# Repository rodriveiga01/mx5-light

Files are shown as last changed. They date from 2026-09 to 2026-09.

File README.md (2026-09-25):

# NA-Wink

Prototype controller for MX-5 pop-up headlights: ESP32 firmware, hardware
design, and companion app.

- `firmware/` — controller, BLE protocol, and host model.
- `hardware/` — harness, pinout, KiCad design, and circuit notes.
- `simulator/` — motor-free behavioral simulation.

Prototype only. Vehicle pinout, wiring, and hardware behavior still need
bench and donor-car validation; see `hardware/kicad/README.md`.

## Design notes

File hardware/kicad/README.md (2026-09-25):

# KiCad design

Sources: `na-wink.kicad_sch` (schematic) and `na-wink.kicad_pcb` (layout
draft). This is a review draft, not fabrication-ready.

- ERC: 0 errors. DRC: 22 unconnected GND items because CLI checks do not fill zones.
- Library remapping is required. Relay footprints are placeholders and must be corrected.
- Connector fit, motor current, relay rating, and relay polarity remain unverified.
- Do not order a board until layout checks and bench validation HV1–HV4 pass.

Reports: `hardware/exports/erc.rpt` and `hardware/exports/drc.rpt`.

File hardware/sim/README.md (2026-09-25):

# Circuit notes

No SPICE run or analog results are available. Motor parameters and validated
vendor models are missing; `protection-frontend.cir.BLOCKED` is a template,
not a runnable simulation.

- `RESULTS.md` — missing measurements and evidence status.
- `tvs-entry-notes.md`, `buck-ldo-notes.md`, `relay-coil-notes.md` — design
  notes only; bench checks are still required.

Enable simulation only after measuring the real motor and adding validated
TVS, buck, and relay models. Save actual results under `hardware/exports/`.

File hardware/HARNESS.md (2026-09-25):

# Harness (plug-and-play, never cut factory wiring)

Two adapter legs sit between the factory connectors and the motors. Relays
de-energized = OEM straight through, so unpowered the car behaves stock
(HV1 validation, NOT RUN).

## Wires (PROPOSED — meter on the donor car before crimping)

| Leg | Wire | Size | Note |
|---|---|---|---|
| A (car) | VBAT | 2.5 mm² + 1.0 pigtail | red, fused 10 A on module |
| A | GND | 2.5 mm² + 1.0 pigtail | black, chassis star bolt |
| A | OEM_L_A/B, OEM_R_A/B | 1.5 mm² + 1.0 pigtail | twisted pairs, < 60 cm |
| A | BTN_SENSE | 0.5 mm² | yellow, opto tap only, 0.5 A inline fuse |
| B (motors) | MOT_x_A/B | 1.5 mm² + 1.0 pigtail | relay common to motor |
| B | SHIELD/GND | 0.5 mm² | drain at module end only |

Rule: NEVER crimp 2.5/1.5 mm² into an MX120G terminal (family max 1.0 mm²).
Join runs to pigtails with ultrasonic splice + adhesive heat-shrink, 10 joints.

## Connectors (candidates — fit NOT verified, meter before mating)

| Ref | Module side | Mating side |
|---|---|---|
| J1 | MX120G 8-pos sealed plug | 8-pos receptacle + terminals + cavity plugs |
| J2/J3 | MX120G 3-pos | matching 3-pos + terminals |
| J_PROG | 1x06 P2.54 header | bench jumpers only |

## Build rules

1. Crimp with the manufacturer tool, pull-test every crimp. Never solder terminals.
2. Sealed shells + cavity plugs on empty positions; loom + boots on both shells.
3. Label every leg (L / R / CAR / MOTOR). Removal = unplug, no trace remains.
4. Verify unpowered: < 1 Ω OEM→MOT per pole, > 10 MΩ pin-to-shell.

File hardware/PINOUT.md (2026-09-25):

# Pinout (PROPOSED — meter every conductor before mating)

## J1 — car side (8-pos sealed)

| Pin | Signal | Note |
|---|---|---|
| 1 | VBAT | fused 10 A on module |
| 2 | GND | chassis star point |
| 3–4 | OEM_L_A / OEM_L_B | relay NC poles |
| 5–6 | OEM_R_A / OEM_R_B | relay NC poles |
| 7 | BTN_SENSE | opto tap, high-Z only |
| 8 | AUX_GND (RESERVED) | unconnected — do NOT wire buttons here |

## J2/J3 — motor sides

| Pin | Signal | Note |
|---|---|---|
| 1–2 | MOT_x_A / MOT_x_B | relay common (NC = OEM, NO = drive) |
| 3 | SHIELD/GND | drain |

NC = de-energized OEM path. Check: pin numbering vs shell keying, NC/NO
orientation, coil polarity + flyback direction, TVS at entry, fuse access.

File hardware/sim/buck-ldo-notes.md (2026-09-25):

# Buck and LDO notes

Proposed supply: protected 12 V → 5 V buck (LM46002-Q1) → 3.3 V LDO
(KF33BD-class). Relay coils use 5 V; the MCU uses 3.3 V. Values and parts
must be checked against datasheets before build.

- Use the buck datasheet design for inductor and compensation; verify load
  steps and 3.3 V stability on the bench.
- Check 3.3 V temperature and regulation during a 60 °C, 30-minute soak.
- Standby target is under 5 mA; not measured.

No SPICE result is claimed. Vendor transient models and bench measurements
are not available.

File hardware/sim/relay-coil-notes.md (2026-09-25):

# Relay coil notes

Four 5 V relay coils use NPN low-side drivers and flyback diodes. GPIO LOW
should leave each relay de-energized on the OEM path; confirm boot behavior
with a scope before vehicle use.

The proposed 560 Ω base resistor improves drive margin over 1 kΩ, but coil
current and transistor saturation must be checked against the final relay
datasheet. Relay and motor inrush behavior is unmeasured. Firmware staggers
commands by at least 150 ms; this does not replace hardware validation.

No SPICE result is claimed. Confirm coil data and suppression on the bench.

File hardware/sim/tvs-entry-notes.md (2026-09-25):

# Power-entry protection notes

Proposed path: J1 → 10 A fuse → reverse-battery block → protected 12 V rail.
A bidirectional SMBJ26CA TVS clamps the rail; place it near the connector.
The TVS is for fast transients, not sustained load dump.

- Published SMBJ26CA clamp: 42.1 V at 14.3 A (10/1000 µs); this does not
  establish protection against longer automotive pulses.
- Confirm reverse-block limits, fuse coordination, and component ratings
  against datasheets and bench tests before vehicle use.
- The 10 A fuse protects the module spur; motors remain on the OEM power path.

No SPICE result is claimed. A sustained transient may damage the TVS; test
protection on a fused, current-limited bench setup.

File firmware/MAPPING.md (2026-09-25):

# Model mapping (Python ↔ C++)

Source of truth: `firmware/model/headlight_controller.py`. The target
`firmware/include/controller_core.h` mirrors it method-for-method
(`boot`, `command`, `dispatch`, `expand`, `tick`, `oem_press`, aux…).
Rule: change behavior in BOTH, plus tests. `test_host_cpp/` compiles the
real C++ header with `g++` and runs assertions (logic only, no GPIO proof).

Key constants (PROPOSED defaults, NOT measured): full travel 3.2 s,
overtime trip at max(dur×1.4, 5 s), WDT 2 s, stagger 150 ms, rate ≤10/s,
lockout 5 s, sleepy 0–100. Target-only glue (`main.cpp`: GPIO order,
relay polarity, HW watchdog, NimBLE, NVS) is code-reviewed only —
unverified without ESP32 hardware and bench scope captures (HV2).

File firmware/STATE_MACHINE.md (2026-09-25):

# State machine

`OEM_PASS → IDLE → MOVING → IDLE`. Overtime → `FAULT` (needs `clear`).
Boot / power-loss / WDT reset → outputs de-energized (relays rest on the
OEM bypass), queue cleared, state `OEM_PASS`.

- Commands queue with 150 ms stagger, never parallel inrush. `stop` cancels.
- BLE disconnect cancels the queue; the in-flight move finishes, then IDLE.
- Bad/unauthenticated commands are rejected + counted, motors never move.
- OEM retractor presses: 1 = stock, 2–9 = mapped action after the gap window.
- Aux buttons: momentary or latching loop; second press (or `stop`) cancels.

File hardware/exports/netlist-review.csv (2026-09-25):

net | schematic_label | pcb_net_id | notes
VBAT | J1.1->F1 | 1 | fused feed | 2.5mm2 intent
GND | star point | 2 | B.Cu plane | chassis bolt
12V_PROTECTED | F1->TVS->buck | 5 | after reverse block + TVS
5V | buck out -> LDO in | 4 | relay coils rail
3V3 | LDO out -> MCU | 3 | MCU + pullups | 100nF per pin intent
N_SW | U_BUCK.3 -> L_BUCK | 33 | buck switch node (unlabeled wire) | inductor input
OEM_L_A | J1.3 NC K1 | 10 | de-energized straight-through
OEM_L_B | J1.4 NC K2 | 11 | twisted pair intent
OEM_R_A | J1.5 NC K3 | 12 | de-energized straight-through
OEM_R_B | J1.6 NC K4 | 13 | twisted pair intent
MOTOR_L_A | K1 COM -> J2.1 | 6 | 2.0mm track | stall TBD HV3
MOTOR_L_B | K2 COM -> J2.2 | 7 | 2.0mm track | stall TBD HV3
MOTOR_R_A | K3 COM -> J3.1 | 8 | 2.0mm track | stall TBD HV3
MOTOR_R_B | K4 COM -> J3.2 | 9 | 2.0mm track | stall TBD HV3
RELAY_L_COIL_A | GPIO4 via Q1 | 14 | NPN low-side | LOW=off
RELAY_L_COIL_B | GPIO5 via Q2 | 15 | flyback D2
RELAY_R_COIL_A | GPIO6 via Q3 | 16 | NPN low-side | LOW=off
RELAY_R_COIL_B | GPIO7 via Q4 | 17 | flyback D4
BTN_SENSE | J1.7 via opto -> GPIO9 | 18 | high-Z tap only + D5 antiparallel revprot (D-05 rev 0.3.3)
AUX1 | GPIO14 via 10k pullup | 19 | active-low pullup (R_AUX1 rev 0.3)
AUX2 | GPIO21 via 10k pullup | 20 | active-low pullup (R_AUX2 rev 0.3)
TX0 | J_PROG.1 prog header | 34 | MCU-side mating at routing
RX0 | J_PROG.2 prog header | 35 | MCU-side mating at routing
BOOT | J_PROG.3 prog header | 36 | MCU-side mating at routing
EN | J_PROG.6 prog header | 37 | MCU-side mating at routing

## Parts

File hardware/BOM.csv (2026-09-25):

RefDes | Qty | Value/Package | Manufacturer/MPN | Alternative | Rating/Notes | Status | Purpose | PackageDetail | Evidence/Source | Validation
F1 | 1 | 10A blade fuse (ATO) | Littelfuse 0297010 / Bourns CF-2 equivalent | Any 10A ATO fuse from an established maker (verify datasheet; no qualification claimed) | Vehicle RETRACT-domain feed; keep holder accessible | PROPOSED - verify fuse coordination with HEAD 30A / RETRACT 30A upstream | Module overcurrent clear | ATO blade + inline holder | Littelfuse 0297 datasheet (review at order); TI TIDA-01167 fuse concept | NEEDS PHYSICAL VALIDATION (HV4 fuse-clear)
FH1 | 1 | ATO fuse holder sealed | Littelfuse 0358-series / TE equivalent | Any sealed ATO holder | 30V DC min; accessible for service disconnect | PROPOSED | Fuse mounting + service disconnect | Panel/inline sealed | Maker datasheet at order | NEEDS DATASHEET REVIEW
D_REV | 1 | Ideal-diode / N-MOSFET reverse-polarity block | TI LM5050-1 + CSD18532KCS (OR-ing reverse block - NOT the TIDA-01167 LM5060-Q1 circuit - attribution corrected 2026-09-23) | LM5050-1-Q1 automotive controller equivalent + 100 V-Vds-class N-FET REQUIRED (see notes) | Blocks reverse battery / jump-start reversal. Headroom verified ONLY for jump-start 24 V + reverse -14 V (LM5050-1 100 V abs, CSD18532KCS 60 V Vds). D-04 attack-session finding rev 0.3.3: unsuppressed dump (101 V) puts LM5050 IN at 101 V (> 100 V abs) and FET Vds ~59 V (~60 V abs); EFT +100 V puts Vds ~58 V. Margin 1-2 V is NOT headroom - LAB must confirm, and the FET MUST be 100 V Vds class at order (drop-in, no copper change). | PROPOSED - PARTIALLY RESOLVED (OE-01 voltage review; HV4 + LAB still required) | Reverse-battery block | SOT-6 (LM5050-1) + TO-220 (100 V Vds N-FET | footprint remap at GUI per OE-12) | TI LM5050-1 Rev F + FET datasheet at order (Vds >= 100 V | Rds <= 5 mohm | LM5050-compatible gate); TIDA-01167 TIDUC41A as protection-concept reference only; eng/transients.py D-04 | NEEDS PHYSICAL VALIDATION (HV4 reverse + LAB dump)
TVS1 | 1 | SMBJ26CA bidirectional TVS (600 W 10/1000 us class) | Littelfuse SMBJ26CA | SMAJ26CA equivalent | Vrwm 26 V / Vbr 28.9-31.9 V @1 mA / Vc 42.1 V @ Ipp 14.3 A (Littelfuse SMBJ series; cross-verified 2026-09-24 Littelfuse/ST/Brightking). No 26V-Vrwm avalanche TVS clamps below 38 V at any surveyed power class (400W-7000W - see PROTECTION_ANALYSIS). Rev 0.3.2: buck is LM46002-Q1 (65 V abs) so Vc 42.1 V coordinates with margin; SMBJ remains ESD/fast-transient class NOT a long-dump absorber - unsuppressed dump stays sacrificial-safe (TVS short -> F1 clears) + LAB. Compliance NOT claimed. | PROPOSED - PARTIALLY RESOLVED (OE-01: coordination via buck selection; energy/LAB still required) | Transient clamp at entry | DO-214AA (SMB) | Littelfuse SMBJ series + ST DS1283 Rev 14 + TI LM46002-Q1 SNVSAA2B (verified 2026-09-24) | HV4 transient + LAB pulse-generator confirmation still required (OE-01)
U_BUCK | 1 | Buck converter 12V->5V 2A automotive | TI LM46002-Q1 (rev 0.3.2 OE-01 resolution; replaces LMR33630) | LM46002A-Q1 PFM variant (same datasheet SNVSAA2B); LM65625-Q1 (TI successor 65V/2.5A - reviewer pointer only NOT evaluated here) | 3.5-60 V operating / 65 V abs max VIN (SNVSAA2B Rev B 2017-07-14 S6.1/S6.3 verified 2026-09-24); TI part qualification only NOT a product claim; 2 A sync; 27 uA Iq. TVS Vc 42.1 V now WITHIN operating range (margin 17.9 V) and abs max (margin 22.9 V). Two-stage lesson kept. Inductor/compensation per datasheet at bench; precision-enable UVLO programming at bring-up. | PROPOSED - PARTIALLY RESOLVED (OE-01: voltage coordination by construction; LAB still required) | 5V rail for coils | HTSSOP-16 PWP (footprint remap at GUI per OE-12) | TI LM46002-Q1 datasheet SNVSAA2B Rev B (verified 2026-09-24); LM46002PWPEVM reference | HV4 transient + LAB pulse-generator confirmation + HV5/HV6 load/thermal still required (OE-01)
L_BUCK | 1 | Buck inductor per U_BUCK datasheet (wired SW->L->5V node rev 0.3; was floating in sch) | Coilcraft / Bourns per buck datasheet | Per buck reference design | Saturation current >= 2x load intent; verify at bench | PROPOSED | Buck energy storage | SMD power inductor | Buck datasheet reference design | NEEDS DATASHEET REVIEW
U_LDO | 1 | LDO 5V->3.3V 1A | ST KF33BD-TR class (as OpenWink rev1/2) | AP2112K-3.3 / TLV1117LV33 | Feeds ESP32-S3. Two-stage keeps dissipation low. Verify thermal at 70C ambient. | PROPOSED | 3V3 MCU rail | SOT-223 | ST KF33BD datasheet (review) | NEEDS PHYSICAL VALIDATION (HV6 thermal)
U_MCU | 1 | ESP32-S3-WROOM-1 module | Espressif ESP32-S3-WROOM-1-N8 | ESP32-S3-WROOM-1-N16R2 | Coded-PHY BLE; NVS settings; HW watchdog 2 s. Firmware in firmware/src/main.cpp. | PROPOSED | Control + BLE + NVS | Castellated module 2x20 | Espressif module datasheet (review at order) | NEEDS PHYSICAL VALIDATION (flash + bench HV2)
K1 | 1 | DPDT relay 5V coil LEFT-A | Omron G2R-2-DC5 | TE RT-series DPDT 5V-coil equivalent (exact variant TBD at order - verify pinout + DC rating) | NC = OEM pass-through (fail-safe); NO = MCU drive. 5A@30VDC resistive per G2R datasheet; DC inductive motor-load rating + stall TBD at HV3 - do NOT downrate. | PROPOSED - confirm against measured stall | Left polarity leg A | THT DPDT (footprint remap at GUI) | Omron G2R datasheet (coil current + contact rating review; read exact 5V-coil current at order) | NEEDS PHYSICAL VALIDATION (HV1 continuity + HV3 stall)
K2 | 1 | DPDT relay 5V coil LEFT-B | Omron G2R-2-DC5 | TE RT-series DPDT 5V-coil equivalent (exact variant TBD at order - verify pinout + DC rating) | Pairs with K1 as reversing pair; both-high inhibited in firmware. 5A@30VDC resistive; DC inductive rating TBD at HV3. | PROPOSED - confirm against measured stall | Left polarity leg B | THT DPDT (footprint remap at GUI) | Omron G2R datasheet | NEEDS PHYSICAL VALIDATION (HV1/HV3)
K3 | 1 | DPDT relay 5V coil RIGHT-A | Omron G2R-2-DC5 | TE RT-series DPDT 5V-coil equivalent (exact variant TBD at order - verify pinout + DC rating) | NC = OEM pass-through; NO = MCU drive. 5A@30VDC resistive; DC inductive rating TBD at HV3. | PROPOSED - confirm against measured stall | Right polarity leg A | THT DPDT (footprint remap at GUI) | Omron G2R datasheet | NEEDS PHYSICAL VALIDATION (HV1/HV3)
K4 | 1 | DPDT relay 5V coil RIGHT-B | Omron G2R-2-DC5 | TE RT-series DPDT 5V-coil equivalent (exact variant TBD at order - verify pinout + DC rating) | Pairs with K3; staggered vs left (>=150 ms). 5A@30VDC resistive; DC inductive rating TBD at HV3. | PROPOSED - confirm against measured stall | Right polarity leg B | THT DPDT (footprint remap at GUI) | Omron G2R datasheet | NEEDS PHYSICAL VALIDATION (HV1/HV3)
Q1-Q4 | 4 | NPN low-side coil driver MMBT2222A | Onsemi MMBT2222A | BC847 equivalent | 1k base from 3V3 GPIO; 5V-coil current TBD from G2R datasheet at order - re-verify saturation margin + HV2 coil check; verify coil current < 150 mA. | PROPOSED | Relay coil switches | SOT-23 x4 | Onsemi MMBT2222A datasheet | NEEDS DATASHEET REVIEW + HV2 coil check
R1-R4 | 4 | Base resistor 560R 0603 1% (D-07 attack-session change | was 1k) | Yageo RC0603FR-07560R series (verify exact MPN at order) | Any 0603 560R 1% | Ib ~4.5 mA nominal; worst-corner saturation margin 1.42 (was 0.80 at 1k - cold + hFE-min + VOH-droop corner desaturated; see eng/monte_carlo.py). GPIO source ~4 mA within ESP32-S3 capability. | PROPOSED | NPN base drive | 0603 | Maker datasheet (generic) + eng/monte_carlo.py worst-case | HV2 coil check (Vce sat scope)
R_AUX1-R_AUX2 | 2 | Pullup resistor 10k 0603 1% (AUX active-low sense) | Yageo RC0603FR-0710KL | Any 0603 10k 1% | External pullups harden off-board switch sense vs MCU 45k internal only (added rev 0.3; kills ERC pin_not_driven). | PROPOSED | AUX sense pullups | 0603 | Maker datasheet (generic) | DESIGN REVIEW
D1-D4 | 4 | Flyback diode 1N4148 | Vishay 1N4148 | 1N4148W equivalent | Across each coil (cathode to 5V side); verify orientation at review. | PROPOSED | Coil suppression | SOD-123 x4 | Vishay 1N4148 datasheet | DESIGN REVIEW + HV2 scope check
D5 | 1 | 1N4148 antiparallel opto-input reverse protection (D-05 attack-session addition rev 0.3.3) | Vishay 1N4148 | 1N4148W equivalent | Across opto LED input (K to BTN_SENSE, A to GND); clamps reverse to ~0.7 V, inert forward. REQUIRED because 4N25 LED abs max VR is 5-6 V (Vishay datasheet) while reverse battery can impose ~14 V across R_SENSE + LED. | PROPOSED | Opto reverse protection | SOD-123 | Vishay 4N25 VR abs max (verified 2026-09-24 via manufacturer datasheet); eng/transients.py | HV4 reverse confirm
U_OPTO_BTN | 1 | Optocoupler 4N25-class BTN_SENSE | Onsemi 4N25 | Vishay 4N25-X009 | High-Z tap + series ~590R class (meter first). Sense only - never drive. | PROPOSED | Retractor-switch sense | DIP-6 | Onsemi 4N25 datasheet; OpenWink rev3 590R note (reference) | NEEDS PHYSICAL VALIDATION (metered levels HV2)
R_SENSE | 1 | Series resistor per metered levels (~590R class intent) | Yageo RC0603 series | TBD after metering | Values set AFTER donor-car metering; do NOT stuff blindly. | PROPOSED - values TBD by metering | Opto input conditioning | 0603 | Donor-car measurement (NOT RUN) | BLOCKED until metering
J1 | 1 | 8-pos sealed automotive connector MX120G-class intent | Molex MX120G-series 8-pos (sealed) | JST / TE sealed 8-pos equivalent | Sealed - vehicle side. PROPOSED candidate only; shell/terminal P/N + keying NEEDS-MEASUREMENT. PARTIALLY RESOLVED (OE-02 rev 0.3.2): MX120G max 1.0 mm2 (Molex family page + PS-36790-001 verified 2026-09-24) - 2.5/1.5 runs join via 1.0 mm2 FLRY-B pigtails + ultrasonic splice + TE SCT seal (see HARNESS.md); direct crimp of 2.5/1.5 PROHIBITED; run-gauge sizing still TBD on measured stall. | PROPOSED - PARTIALLY RESOLVED (OE-02 mechanical; electrical sizing TBD) | Vehicle harness interface | MX120G 8-pos + 36799-series terminals + seals | Molex MX120G 36783/36792/36799 + PS-36790-001 (verified 2026-09-24; 1.0mm2 grip P/N per SD-36799-001 at order) | Mating on donor car + run-gauge sizing on measured stall still required (OE-02)
J2-J3 | 2 | Motor-side sealed 3-pos connectors | Molex MX120G-series 3-pos | Matching sealed series | To each retractor motor pigtail via plug-and-play adapter. PARTIALLY RESOLVED (OE-02 rev 0.3.2): 1.5 mm2 MOT runs join via 1.0 mm2 pigtails + ultrasonic splice + TE SCT seal (see HARNESS.md); direct crimp of 1.5 PROHIBITED; run-gauge sizing still TBD on measured stall. | PROPOSED - PARTIALLY RESOLVED (OE-02 mechanical; electrical sizing TBD) | Motor pigtail adapters | MX120G 3-pos + 36799-series terminals + seals | Molex MX120G + PS-36790-001 (verified 2026-09-24) | Mating + run-gauge sizing on measured stall still required (OE-02)
J_PROG | 1 | Programming header 1x06 P2.54 (6-pin symbol rev 0.3; was 3-pin placeholder) | Samtec / generic 1x06 header | Any 2.54mm header | TX/RX/3V3/GND/EN/BOOT for flashing + diagnostics. | PROPOSED | Flash + debug | THT 1x06 | Generic (review) | DESIGN REVIEW
C_BULK | 2 | 470uF 50V electrolytic (uprated rev 0.3.2 OE-01) | Nichicon UHW-series 50V | Any 105C-rated 50V equivalent | Bulk for inrush / ride-through. Uprated because TVS clamp 42.1 V exceeds the former 35 V rating (clamp arithmetic 2026-09-24). ESR + ripple to confirm. | PROPOSED | Bulk ride-through | Radial (footprint remap at GUI per OE-12) | Nichicon UHW datasheet (verify 50V series at order) | NEEDS PHYSICAL VALIDATION (HV2 inrush)
C_DEC | 5 | 100nF 50V ceramic per rail + MCU pins (C_DEC1/2 3V3, C_DEC3-5 5V; placed rev 0.3) | Murata GRM155-series | Any X7R 100nF | One per rail + per MCU supply pin intent. | PROPOSED | Decoupling | 0603 | Murata datasheet (generic) | DESIGN REVIEW
TP_x | 8 | Test points TP_VBAT TP_3V3 TP_5V TP_COIL TP_MOT TP_GND | Keystone 5000-series | Any through-hole loop | HV1-HV4 measurement points near J1 edge. | PROPOSED | Bench measurement | TH loop | Keystone datasheet | DESIGN REVIEW
PCB | 1 | 2-layer FR-4 100x70mm 1.6mm 1oz Cu | JLCPCB / PCBWay class fab | - | Motor tracks 2.0mm; star GND; TVS at entry. NOT fabrication-ready: ERC 0 errors + DRC 0 shorting/clearance/crossing/edge (2026-09-23 GND zone-fill artifact); GUI remap/fill + HV1-HV4 still required. | REVIEW DRAFT | Module substrate | 100x70mm 2L 1oz | hardware/kicad/ review draft | ERC/DRC run 2026-09-23 (see STATUS.txt); BLOCKED until GUI remap/fill + HV1-HV4
ENC | 1 | Parametric enclosure (OpenSCAD hardware/cad/enclosure.scad) | Printed ASA prototype (Bambu-class) or ABS | - | Prototype material ONLY. NOT automotive-qualified; thermal/moisture/vibration limits in SAFETY_CASE. | PROTOTYPE ONLY | Dust/touch protection on bench | Printed ASA/ABS | SAFETY_CASE H6 limits | NOT automotive-qualified by design

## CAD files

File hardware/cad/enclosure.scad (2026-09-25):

// SPDX-License-Identifier: GPL-3.0-or-later
// Parametric enclosure for the NA wink controller (prototype intent).
// Prototype material (ASA/ABS print) ONLY - NOT automotive-qualified.
// See docs/SAFETY_CASE.md for thermal / moisture / vibration limits.
// Validate with: parser check in scripts/verify.sh (mesh render needs OpenSCAD).
//
// Contents: PCB mounting (4x M3 bosses + inserts), relay clearance dome,
// connector clearance cutouts (J1/J2/J3), cable exits (16 mm gland + boots),
// internal strain-relief posts, chassis mounting ears, tilt drain, service
// lid with fasteners, status-LED window (DEFERRED/NON-FUNCTIONAL in rev 0.3.1:
// no LED in BOM/schematic — do NOT rely on it), fuse-access hatch (service
// disconnect without opening the case).
//
// Placement: cabin/footwell REQUIRED (never engine bay). Connectors DOWN
// (drip). Fuse holder reachable from outside.
// Print: ASA/ABS, 0.2 mm layers, 4 walls, 40% gyroid (prototype only).

// --- Parameters (mm) ---
pcb_l = 100; pcb_w = 70; pcb_t = 1.6;
wall = 2.5; lid_t = 2.0; clearance_xy = 1.5; clearance_z = 8;
boss_d = 6.0; boss_hole_d = 3.2;           // M3 self-tap / insert
gland_d = 16.0;                             // cable gland entry
drain_d = 3.0;                              // tongue-and-groove tilt drain corner
strain_post_d = 8.0;
relay_dome_h = 6.0;                         // extra clearance over K1-K4 bank
conn_cut_w = 30.0; conn_cut_h = 12.0;       // J1/J2/J3 face cutouts
ear_w = 12.0; ear_hole_d = 4.2;             // M4 chassis ears
led_win_d = 4.0;                            // deferred LED window (NON-FUNCTIONAL rev 0.3.1 — geometry kept, no LED fitted)
fuse_hatch_w = 20.0; fuse_hatch_h = 14.0;   // F1 service hatch
lid_screw_d = 3.2; lid_insert_d = 4.0;      // M3 lid screws + inserts

inner_l = pcb_l + 2*clearance_xy;
inner_w = pcb_w + 2*clearance_xy;
outer_l = inner_l + 2*wall;
outer_w = inner_w + 2*wall;
base_h = clearance_z + pcb_t + 6;           // room for relays + buck inductor

module body() {
  difference() {
    // outer body
    cube([outer_l, outer_w, base_h + lid_t], center=false);
    // cavity
    translate([wall, wall, wall])
      cube([inner_l, inner_w, base_h + lid_t], center=false);
    // relay clearance dome (over K1-K4 bank, center-right of PCB)
    translate([outer_l*0.35, outer_w*0.45, base_h - relay_dome_h])
      cube([outer_l*0.5, outer_w*0.4, relay_dome_h + lid_t + 1], center=false);
    // cable entry (gland side, +X face)
    translate([outer_l - 1, outer_w/2, wall + 4])
      rotate([0, 90, 0])
      cylinder(d=gland_d, h=wall + 2, $fn=32);
    // connector face cutouts (J1/J2/J3 edge, -X face)
    translate([-1, outer_w*0.25, wall + 2])
      cube([wall + 2, conn_cut_w, conn_cut_h], center=false);
    // fuse service hatch (top edge near F1 corner)
    translate([wall + 6, -1, base_h - fuse_hatch_h/2])
      cube([fuse_hatch_w, wall + 2, fuse_hatch_h], center=false);
    // deferred status-LED window (lid-adjacent wall; NON-FUNCTIONAL rev 0.3.1)
    translate([wall + inner_l - 10, outer_w - 1, base_h - 4])
      rotate([90, 0, 0])
      cylinder(d=led_win_d, h=wall + 2, $fn=16);
    // tilt drain at -X/-Y corner
    translate([wall + 6, wall + 6, -0.5])
      cylinder(d=drain_d, h=wall + 1, $fn=16);
    // lid screw counterbores x4
    for (x = [wall + 4, wall + inner_l - 4])
      for (y = [wall + 4, wall + inner_w - 4])
        translate([x, y, base_h + lid_t - 1])
          cylinder(d=lid_screw_d + 1.6, h=2, $fn=16);
  }
  // PCB bosses x4 (M3 inserts)
  for (x = [wall + 4, wall + inner_l - 4])
    for (y = [wall + 4, wall + inner_w - 4])
      difference() {
        translate([x, y, wall]) cylinder(d=boss_d, h=6, $fn=24);
        translate([x, y, wall]) cylinder(d=boss_hole_d, h=7, $fn=16);
      }
  // strain-relief posts near gland
  translate([outer_l - wall - 12, outer_w/2 - 10, wall])
    cylinder(d=strain_post_d, h=8, $fn=24);
  translate([outer_l - wall - 12, outer_w/2 + 10, wall])
    cylinder(d=strain_post_d, h=8, $fn=24);
  // chassis mounting ears x2 (-X/+X)
  for (sx = [-ear_w, outer_l])
    difference() {
      translate([sx, outer_w/2 - 10, 0]) cube([ear_w, 20, wall], center=false);
      translate([sx + ear_w/2, outer_w/2, -0.5])
        cylinder(d=ear_hole_d, h=wall + 1, $fn=16);
    }
}

module lid() {
  translate([0, 0, base_h + lid_t]) {
    difference() {
      cube([outer_l, outer_w, lid_t], center=false);
      // tongue-and-groove channel (mating ridge on body implied)
      translate([wall/2, wall/2, -1])
        cube([outer_l - wall, outer_w - wall, 1.5], center=false);
      // lid screw through-holes x4 (match body counterbores)
      for (x = [wall + 4, wall + inner_l - 4])
        for (y = [wall + 4, wall + inner_w - 4])
          translate([x, y, -0.5])
            cylinder(d=lid_screw_d, h=lid_t + 1, $fn=16);
    }
  }
}

body();
lid();

// echo key dims for verify.sh parser check
echo(str("OUTER ", outer_l, " x ", outer_w, " x ", base_h + lid_t));
echo(str("NOT automotive-qualified - prototype ASA/ABS only"));

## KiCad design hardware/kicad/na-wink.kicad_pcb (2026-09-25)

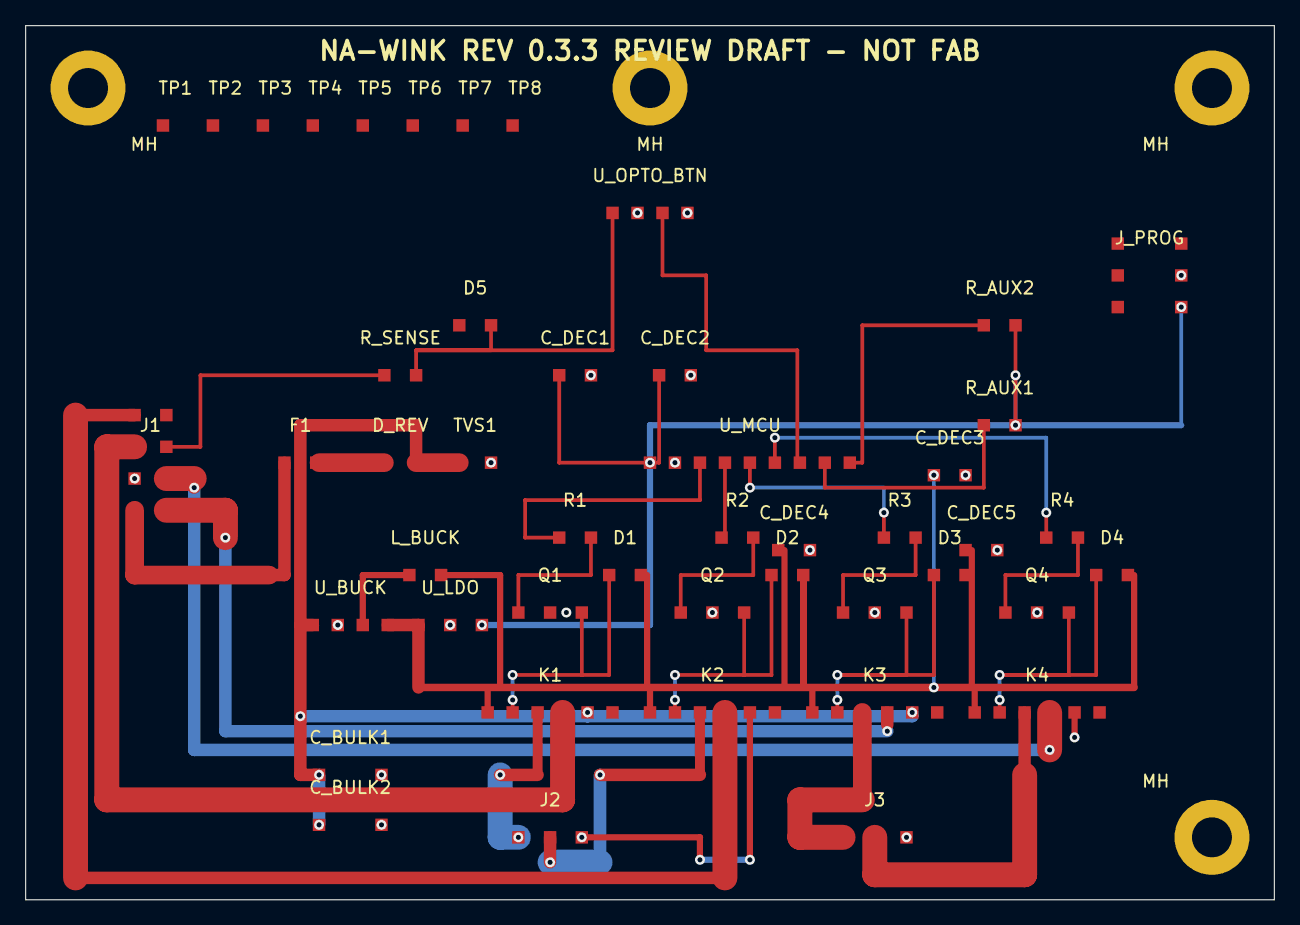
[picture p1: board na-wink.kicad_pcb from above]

Board: 2 copper layers, 100.0 x 70.0 mm, 51 parts (0 on the bottom side), 32 nets.

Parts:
C_BULK1, C_BULK2: 470uF-50V; CP_Radial_D10
C_DEC1, C_DEC2, C_DEC3, C_DEC4, C_DEC5: 100nF-50V; C_0603
D1, D2, D3, D4: 1N4148-flyback; D_SOD-123
D5: 1N4148-revprot; D_SOD-123
D_REV: LM5050-ideal-diode-TBD; D_REV-LM5050-CSD18532-TBD
F1: 10A-ATO; ATO-blade
J1: MX120G-8
J2: MOTOR-L; MX120G-3
J3: MOTOR-R; MX120G-3
J_PROG: PROG; PinHeader_1x06
K1, K2, K3, K4: G2R-2-DC5; Omron_G2R-2
L_BUCK: 4U7; LX_4U7_TBD
MH: M3; MountingHole_3.2mm_M3
MH#2, MH#3, MH#4: M3; MountingHole_3.2mm_M3
Q1, Q2, Q3, Q4: MMBT2222A; SOT-23
R1, R2, R3, R4: 560R-0603; R_0603
R_AUX1, R_AUX2: 10k-0603; R_0603
R_SENSE: 590R-TBD-METERING; R_0603
TP1, TP2, TP3, TP4, TP5, TP6, TP7, TP8: TP; Loop_D2.5
TVS1: SMBJ26CA; Diodes_SMB
U_BUCK: LM46002; Buck-12V-5V
U_LDO: KF33BD; SOT-223
U_MCU: ESP32-S3; ESP32-S3-WROOM-1
U_OPTO_BTN: 4N25; DIP-6

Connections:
3V3: C_DEC1.1, C_DEC2.1, J_PROG.4, R_AUX1.2, R_AUX2.2, U_LDO.3, U_MCU.1
5V: C_DEC3.1, C_DEC4.1, C_DEC5.1, D1.2, D2.2, D3.2, D4.2, K1.1, K2.1, K3.1, K4.1, L_BUCK.2, U_BUCK.4, U_LDO.1
12V_PROTECTED: C_BULK1.1, C_BULK2.1, D_REV.2, K1.5, K3.5, TVS1.1, U_BUCK.1
AUX1: R_AUX1.1, U_MCU.8
AUX2: R_AUX2.1, U_MCU.9
BTN_SENSE: D5.2, R_SENSE.2, U_OPTO_BTN.1
GND: C_BULK1.2, C_BULK2.2, C_DEC1.2, C_DEC2.2, C_DEC3.2, C_DEC4.2, C_DEC5.2, D5.1, J1.2, J2.3, J3.3, J_PROG.5, K2.5, K4.5, Q1.2, Q2.2, Q3.2, Q4.2, TVS1.2, U_BUCK.2, U_LDO.2, U_MCU.2, U_OPTO_BTN.2, U_OPTO_BTN.4
MOTOR_L_A: J2.1, K1.3
MOTOR_L_B: J2.2, K2.3
MOTOR_R_A: J3.1, K3.3
MOTOR_R_B: J3.2, K4.3
N_G4R1: R1.1, U_MCU.3
N_G5R2: R2.1, U_MCU.4
N_G6R3: R3.1, U_MCU.5
N_G7R4: R4.1, U_MCU.6
N_J1_RSENSE: J1.7, R_SENSE.1
N_R1Q1: Q1.1, R1.2
N_R2Q2: Q2.1, R2.2
N_R3Q3: Q3.1, R3.2
N_R4Q4: Q4.1, R4.2
N_SENSE9: U_MCU.7, U_OPTO_BTN.3
N_SW: L_BUCK.1, U_BUCK.3
OEM_L_A: J1.3, K1.4
OEM_L_B: J1.4, K2.4
OEM_R_A: J1.5, K3.4
OEM_R_B: J1.6, K4.4
RELAY_L_COIL_A: D1.1, K1.2, Q1.3
RELAY_L_COIL_B: D2.1, K2.2, Q2.3
RELAY_R_COIL_A: D3.1, K3.2, Q3.3
RELAY_R_COIL_B: D4.1, K4.2, Q4.3
VBAT: F1.1, J1.1
VBAT_FUSED: D_REV.1, F1.2

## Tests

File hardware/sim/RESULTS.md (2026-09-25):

# Simulation results

None. No ngspice run has been performed; the Python simulator and host tests
do not model analog behavior.

Blocked on measured motor resistance, inductance, stall/inrush current, and
travel time; validated TVS and buck models; relay coil data; and fuse
coordination. Add these inputs before running the blocked deck. Save raw
output, plots, and a dated report under `hardware/exports/`.

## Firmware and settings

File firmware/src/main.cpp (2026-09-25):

// SPDX-License-Identifier: GPL-3.0-or-later
// NA Wink — ESP32-S3 target firmware (Arduino core + NimBLE).
//
// Control path: portable core in include/controller_core.h (same semantics as
// firmware/model/headlight_controller.py, see MAPPING.md). This file is the
// TARGET GLUE: GPIO init/safe boot, relay mapping, HW watchdog, motion
// timeout/overtime via core tick, BLE GATT + bonding + rate-limit/lockout,
// OEM/aux physical buttons, NVS persistence, diagnostics, safe cancellation.
//
// SAFETY INVARIANTS (enforced here, tested in host model):
//   1. Boot/reset/WDT -> relays DE-ENERGIZED (GPIO LOW on NPN low-side) ->
//      state OEM_PASS. No motion until explicit authenticated command or
//      mapped physical-button action.
//   2. loop() is NON-BLOCKING (no delay()); HW WDT fed every iteration.
//   3. BLE loss cancels pending macro at quantum boundary + cancels aux loops.
//   4. Overtime (>dur*1.4, min 5 s) -> FAULT + de-energize + explicit clear.
//   5. Config changes (sleepy/wave/gap/maps) NEVER auto-move; reboot NEVER
//      auto-moves. Both-high motor drive is inhibited by the queued/staggered
//      core (never parallel inrush by design).
//   6. Motor polarity/stall/limit behavior is UNKNOWN (A1) — isolated behind
//      RELAY_POLARITY_* config + bench HV2/HV3 gates. Do NOT retune blindly.
//
// Build: see firmware/BUILD.md. Host syntax check (verify.sh) compiles this
// file with stubbed Arduino.h (ARDUINO undefined) — all ESP-only includes
// and calls are guarded by #ifdef ARDUINO so the check exercises the portable
// core + glue structure without claiming a target build.

#include "ble_uuids.h"
#include "config.h"
#include "controller_core.h"
#include "persistence.h"

#ifdef ARDUINO
#include <Arduino.h>
#include <NimBLEDevice.h>
#include <esp_task_wdt.h>
#include <Preferences.h>
#else
// ---- Host syntax-check stubs (verify.sh provides Arduino.h with
// pinMode/digitalWrite/delay; complete the minimal surface here) ----
#ifndef HIGH
#define HIGH 1
#endif
#ifndef LOW
#define LOW 0
#endif
#ifndef OUTPUT
#define OUTPUT 1
#endif
#ifndef INPUT_PULLUP
#define INPUT_PULLUP 2
#endif
#ifndef ARDUINO_STUB_EXTRA
#define ARDUINO_STUB_EXTRA
inline void pinMode(int, int) {}
inline void digitalWrite(int, int) {}
inline int digitalRead(int) { return HIGH; }
inline unsigned long millis() { return 0; }
#endif
#endif

// ---------------------------------------------------------------- relay glue
// NPN low-side drivers (BOM Q1-Q4): GPIO LOW = transistor OFF = relay
// de-energized => NC contacts conduct the OEM path. GPIO HIGH energizes the
// coil (takes control). Boot/reset paths ALWAYS drive LOW first.

static nawink::Controller g_ctl;
static nawink::Settings g_settings;

static const int kRelayPins[4] = {RELAY_L_POL1_GPIO, RELAY_L_POL2_GPIO,
                                  RELAY_R_POL1_GPIO, RELAY_R_POL2_GPIO};

// Polarity map: which coil level drives which motor direction.
// PROPOSED default (A1 UNVERIFIED): coil pair (POL1=HIGH,POL2=LOW) = "raise".
// If bench HV2 shows inversion, flip RELAY_POLARITY_INVERT (config, not code).
static const bool RELAY_POLARITY_INVERT = false;

static void relaysDeEnergized() {
#ifdef ARDUINO
  for (int p : kRelayPins) digitalWrite(p, LOW);
#else
  (void)kRelayPins;
#endif
  g_ctl.oem_path_ok = true;
}

static void applyRelayOutputs() {
  // Safe default: everything de-energized unless the core has an active move.
  // The core serializes moves (stagger >=150 ms) so at most one side is
  // driven at a time; both-high is structurally inhibited.
  if (!g_ctl.active.has()) {
    relaysDeEnergized();
    return;
  }
  bool invert = RELAY_POLARITY_INVERT;
#ifdef ARDUINO
  // Drive ONLY the active side; the idle side stays de-energized (OEM live).
  // Direction bit: target 100 (up/raise) vs 0 (down/lower). Exact contact
  // polarity vs motor leads is verified at bench HV2 — this mapping is the
  // single place to correct it.
  bool raise = g_ctl.active.target > 50.0f;
  if (invert) raise = !raise;
  if (g_ctl.active.side == "left") {
    digitalWrite(RELAY_L_POL1_GPIO, raise ? HIGH : LOW);
    digitalWrite(RELAY_L_POL2_GPIO, raise ? LOW : HIGH);
    digitalWrite(RELAY_R_POL1_GPIO, LOW);
    digitalWrite(RELAY_R_POL2_GPIO, LOW);
  } else {
    digitalWrite(RELAY_R_POL1_GPIO, raise ? HIGH : LOW);
    digitalWrite(RELAY_R_POL2_GPIO, raise ? LOW : HIGH);
    digitalWrite(RELAY_L_POL1_GPIO, LOW);
    digitalWrite(RELAY_L_POL2_GPIO, LOW);
  }
#endif
  g_ctl.oem_path_ok = false;  // MCU has taken control of (at least) one side
}

// ------------------------------------------------------- command parser glue
// BLE UTF-8 strings: "up:L|R|B  down:L|R|B  wink:L|R|B  blink:L|R|B
// wave:LR|RL  sleepy:L|R|B  stop  clear" + "L=nn,R=nn" sleepy form.
// Returns true if accepted (queued), false if rejected (counted upstream).
static bool handleBleCommand(const char* cmd, bool authenticated) {
  std::string s(cmd ? cmd : "");
  // Sleepy compact form "L=nn,R=nn" (SLEEPY_EYE char)
  if (s.find('=') != std::string::npos) {
    // Parse "L=40" / "R=60" fragments; each out-of-range rejects the write.
    bool ok = true;
    size_t pos = 0;
    while (pos < s.size()) {
      size_t comma = s.find(',', pos);
      std::string frag = s.substr(pos, comma == std::string::npos ? std::string::npos : comma - pos);
      size_t eq = frag.find('=');
      if (eq == std::string::npos) return false;
      std::string side = frag.substr(0, eq);
      float v = 0;
      try {
        v = std::stof(frag.substr(eq + 1));
      } catch (...) {
        return false;
      }
      // "B" form "B=nn" sets both (checked BEFORE the empty-key reject;
      // audit fix 2026-09-23: the old order returned false for side=="B"
      // first, leaving this branch unreachable dead code).
      if (side == "B") {
        if (!g_ctl.set_sleepy("left", v, authenticated)) ok = false;
        if (!g_ctl.set_sleepy("right", v, authenticated)) ok = false;
      } else {
        std::string key = (side == "L") ? "left" : (side == "R" ? "right" : "");
        if (key.empty()) return false;
        if (!g_ctl.set_sleepy(key, v, authenticated)) ok = false;
      }
      if (comma == std::string::npos) break;
      pos = comma + 1;
    }
    // Sleepy config write NEVER moves motors (invariant 5).
    g_settings.sleepy_l = g_ctl.sleepy["left"];
    g_settings.sleepy_r = g_ctl.sleepy["right"];
    nawink::saveSettings(g_settings);
    return ok;
  }
  return g_ctl.command(s, authenticated);
}

#ifdef ARDUINO
// ------------------------------------------------------- NimBLE target glue
static NimBLEServer* g_server = nullptr;
static bool g_bonded_central = false;
static unsigned long g_pair_window_until = 0;

class MotionCallbacks : public NimBLECharacteristicCallbacks {
  bool authed() { return g_bonded_central && g_ctl.bonded; }
  void onWrite(NimBLECharacteristic* c) override {
    std::string v = c->getValue();
    // Rate-limit + invalid-streak lockout live in the core (tested).
    handleBleCommand(v.c_str(), authed());
  }
};

class PasskeyCallbacks : public NimBLECharacteristicCallbacks {
  void onWrite(NimBLECharacteristic* c) override {
    if (millis() > g_pair_window_until) return;  // window closed
    std::string v = c->getValue();
    // 6-digit format check (matches app validatePasskey + docs).
    // Reconciliation fix 2026-09-23: the old `v.size() == 6` test accepted
    // any 6 characters (e.g. "abcdef"). Comparison against the per-module
    // label key in NVS is still a provisioning step (HANDOFF §12.A11);
    // pairing-attempt rate/lockout + bond persistence are open hardening
    // items, NOT implemented here. Over-the-air MITM limits documented.
    if (nawink::isValidPairingPin(v)) {
      g_ctl.pair(true);
      g_bonded_central = true;
    }
  }
};

void setupBle(const char* devName) {
  NimBLEDevice::init(devName);
  NimBLEDevice::setSecurityAuth(true, true, true);
  g_server = NimBLEDevice::createServer();
  NimBLEService* svc = g_server->createService(WINK_SERVICE_UUID);
  auto* head = svc->createCharacteristic(HEADLIGHT_CHAR_UUID,
                                         NIMBLE_PROPERTY::WRITE | NIMBLE_PROPERTY::WRITE_ENC);
  head->setCallbacks(new MotionCallbacks());
  auto* sleepy = svc->createCharacteristic(SLEEPY_EYE_UUID,
                                           NIMBLE_PROPERTY::WRITE | NIMBLE_PROPERTY::WRITE_ENC);
  sleepy->setCallbacks(new MotionCallbacks());
  auto* custom = svc->createCharacteristic(CUSTOM_COMMAND_UUID,
                                           NIMBLE_PROPERTY::WRITE | NIMBLE_PROPERTY::WRITE_ENC);
  custom->setCallbacks(new MotionCallbacks());
  auto* passkey = svc->createCharacteristic(PASSKEY_UUID, NIMBLE_PROPERTY::WRITE);
  passkey->setCallbacks(new PasskeyCallbacks());
  svc->start();
  NimBLEAdvertising* adv = NimBLEDevice::getAdvertising();
  adv->addServiceUUID(WINK_SERVICE_UUID);
  adv->start();
  g_pair_window_until = millis() + (unsigned long)PAIRING_WINDOW_S * 1000UL;
}
#endif

// ------------------------------------------------------------------ lifecycle
static void safeBootPins() {
  // ORDER MATTERS: mode first, then LOW (off) — reviewed, no strapping pins.
  for (int p : kRelayPins) {
#ifdef ARDUINO
    pinMode(p, OUTPUT);
    digitalWrite(p, LOW);
#else
    (void)p;
#endif
  }
#ifdef ARDUINO
  pinMode(OEM_SENSE_GPIO, INPUT_PULLUP);
  pinMode(AUX1_GPIO, INPUT_PULLUP);
  pinMode(AUX2_GPIO, INPUT_PULLUP);
#endif
}

void setup() {
  safeBootPins();
  relaysDeEnergized();
  g_ctl.boot();  // OEM_PASS, queue cleared, no motion
  g_settings = nawink::loadSettings();
  // Apply persisted config to core WITHOUT moving (invariant 5).
  g_ctl.sleepy["left"] = g_settings.sleepy_l;
  g_ctl.sleepy["right"] = g_settings.sleepy_r;
  g_ctl.wave_delay_s = g_settings.wave_ms / 1000.0f;
  g_ctl.press_gap_s = g_settings.gap_ms / 1000.0f;
  g_ctl.feed_watchdog();
#ifdef ARDUINO
  // HW watchdog 2 s (task supervision); reboot -> setup() -> OEM_PASS again.
  esp_task_wdt_init(WDT_TIMEOUT_MS / 1000, true);
  esp_task_wdt_add(NULL);
  setupBle("Wink-0000");  // PROVISIONING PLACEHOLDER: docs name the device
  // `Wink-<serial>` (label key); the <serial> suffix is assigned at module
  // provisioning (bench). Two unprovisioned modules share this name — pair
  // only one new module at a time (see ENGINEERING_HANDOFF §12).
#endif
}

void loop() {
  // NON-BLOCKING tick: 10 ms quantum keeps WDT + motion-timeout accurate.
  // No delay() in the control path (audit fix retained).
  static unsigned long last_ms = 0;
#ifdef ARDUINO
  unsigned long now = millis();
  float dt = (last_ms == 0) ? 0.01f : (now - last_ms) / 1000.0f;
  if (dt < 0.005f) dt = 0.005f;
  if (dt > 0.05f) dt = 0.05f;
  last_ms = now;
  esp_task_wdt_reset();
  g_ctl.feed_watchdog();  // fed every loop; starvation only on lockup
  // Physical buttons (edge-detected, debounced in target HAL — bench HV2):
  // OEM_SENSE/AUX1/AUX2 active-low. Core methods are synchronous and safe
  // to call here; BLE-loss/reset paths cancel via core.
  g_ctl.tick(dt);
  applyRelayOutputs();
#else
  (void)last_ms;
  // Host syntax-check path: exercise the same core tick ordering.
  g_ctl.tick(0.01f);
  applyRelayOutputs();
#endif
}

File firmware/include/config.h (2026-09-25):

// SPDX-License-Identifier: GPL-3.0-or-later
// NA Wink — ESP32-S3 target configuration (single source of truth for pins
// and timing on target; host model mirrors these values).
//
// GPIO 4-7 are NOT strapping pins on ESP32-S3 (safe for relay drive).
// NC = OEM path. GPIO LOW = coil OFF = OEM bypass (NPN low-side).
// All timing values are PROPOSED defaults (assumption A3) — NOT measured.
// See docs/RESEARCH.md, docs/VERIFICATION_AUDIT.md.
#pragma once

#ifndef FW_VERSION
#define FW_VERSION "0.2.1"
#endif
#define FW_MODEL_MAP "firmware/model/headlight_controller.py -> controller_core.h (see MAPPING.md)"

// ---- Relay drive GPIOs (PROPOSED — verify boot glitch on first article, HV2) ----
#define RELAY_L_POL1_GPIO 4
#define RELAY_L_POL2_GPIO 5
#define RELAY_R_POL1_GPIO 6
#define RELAY_R_POL2_GPIO 7

// ---- Sense / aux inputs (active-low, internal pull-up; PROPOSED) ----
#define OEM_SENSE_GPIO 9    // via 4N25-class opto, high-Z tap (see PINOUT.md)
#define AUX1_GPIO 14
#define AUX2_GPIO 21

// ---- Timing (seconds / ms; PROPOSED defaults, NOT measured) ----
#define FULL_TRAVEL_S 3.2f
#define MOTION_TIMEOUT_MS 5000
#define WDT_TIMEOUT_MS 2000
#define STAGGER_MS 150
#define OVERTIME_FACTOR 1.4f
#define WAVE_DELAY_DEFAULT_MS 350
#define WAVE_DELAY_MIN_MS 100
#define WAVE_DELAY_MAX_MS 1500

// ---- BLE policy ----
#define RATE_LIMIT_PER_S 10
#define LOCKOUT_S 5
#define PAIRING_WINDOW_S 300
#define INVALID_STREAK_LOCKOUT 5

// ---- Sleepy-eye bounds ----
#define SLEEPY_MIN 0
#define SLEEPY_MAX 100

// ---- NVS keys ----
#define NVS_NS "nawink"
#define NVS_KEY_SLEEPY_L "sleepy_l"
#define NVS_KEY_SLEEPY_R "sleepy_r"
#define NVS_KEY_WAVE_MS "wave_ms"
#define NVS_KEY_GAP_MS "gap_ms"
#define NVS_KEY_SETTINGS_VER "cfg_ver"
#define SETTINGS_VERSION 2

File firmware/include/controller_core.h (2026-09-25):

// SPDX-License-Identifier: GPL-3.0-or-later
// NA Wink — portable control core (header-only C++17, no Arduino dependency).
//
// This is the TARGET logic compiled into firmware/src/main.cpp on ESP32-S3
// AND compiled on host with g++ for logic tests (see firmware/test_host_cpp/).
// It is a faithful C++ port of firmware/model/headlight_controller.py.
//
// Mapping contract (Python -> C++ -> test):
//   Controller::boot/power_loss/feed_watchdog/pair/ble_connect/ble_disconnect
//     -> test_controller.py lifecycle tests + test_target_parity.py
//   command/set_sleepy/_dispatch/_expand (up/down/wink/blink/wave/sleepy/stop/clear)
//     -> test_controller.py command tests + parity tests
//   _auth_ok/_rate_ok/invalid-streak/lockout -> parity tests
//   tick (WDT/motion-timeout/overtime/stagger/press-gap/aux-loop)
//     -> parity tests
//   oem_press/_settle_presses/configure_press_gap/map_button
//     -> OEM tests + parity tests
//   aux_press/configure_aux/_pump_loop -> aux tests + parity tests
//
// HARDWARE ABSTRACTION BOUNDARY (explicit unknowns, NOT guessed):
//   - This core NEVER touches GPIO. The target glue in main.cpp maps
//     "active side + target" to relay-coil levels. Motor polarity, stall
//     current, limit-switch behavior are NOT modeled here (assumption A1).
//   - oem_path_ok is an AVAILABILITY FLAG (true when core requests
//     de-energized bypass), NOT a continuity measurement. Real proof is
//     bench HV1/HV4 (NOT RUN).
//   - Timing constants are PROPOSED defaults (A3), not measurements.
//   - Host tests prove LOGIC ONLY. They do NOT prove ESP32 GPIO, NimBLE,
//     NVS, or HW-watchdog behavior (all UNVERIFIED without hardware).
#pragma once

#include <cmath>
#include <cstdint>
#include <deque>
#include <map>
#include <string>
#include <vector>

namespace nawink {

inline constexpr float kFullTravelS = 3.2f;
inline constexpr float kMotionTimeoutS = 5.0f;
inline constexpr float kWdtTimeoutS = 2.0f;
inline constexpr float kStaggerS = 0.15f;
inline constexpr int kRateLimitPerS = 10;
inline constexpr float kLockoutS = 5.0f;
inline constexpr float kOvertimeFactor = 1.4f;
inline constexpr float kValidSleepyLo = 0.0f;
inline constexpr float kValidSleepyHi = 100.0f;
// D-02 attack-session bound (parity with Python LOG_MAX): diagnostic log is
// capped so sustained rate-limit abuse cannot grow the heap unbounded on
// target (failure mode was safe-side reset -> OEM_PASS; now bounded).
inline constexpr std::size_t kLogMax = 128;

enum class State { OEM_PASS, IDLE, MOVING, FAULT };
enum class Side { LEFT, RIGHT };

inline std::string toString(State s) {
  switch (s) {
    case State::OEM_PASS: return "OEM_PASS";
    case State::IDLE: return "IDLE";
    case State::MOVING: return "MOVING";
    case State::FAULT: return "FAULT";
  }
  return "?";
}

struct Headlight {
  float position = 0.0f;  // 0 down .. 100 up
  bool moving = false;
  int last_travel_ms = 0;
};

struct QueuedMove {
  std::string side;  // "left" | "right"
  float target = 0.0f;
  float delay = 0.0f;
};

// Pairing-PIN transport format: exactly 6 ASCII digits.
// Matches app validatePasskey (/^\d{6}$/) + docs ("6-digit passkey").
// FORMAT ONLY: comparison against the per-module label key is a provisioning
// step (HANDOFF §12.A11) and is NOT performed here or in main.cpp yet.
inline bool isValidPairingPin(const std::string& v) {
  if (v.size() != 6) return false;
  for (char c : v)
    if (c < '0' || c > '9') return false;
  return true;
}

struct ActiveMove {
  std::string side;  // "" = none
  float target = 0.0f;
  float t = 0.0f;
  float dur = 0.0f;
  bool has() const { return !side.empty(); }
};

class Controller {
 public:
  Headlight left;
  Headlight right;
  State state = State::OEM_PASS;
  bool oem_path_ok = true;
  bool bonded = false;
  bool ble_connected = false;
  bool bonded_link = false;
  float time_s = 0.0f;
  float wdt_last_feed = 0.0f;
  std::vector<float> cmd_times;
  float lockout_until = 0.0f;
  int invalid_streak = 0;
  std::string fault;
  float wave_delay_s = 0.35f;
  std::map<std::string, float> sleepy{{"left", 50.0f}, {"right", 50.0f}};
  std::deque<QueuedMove> queue;
  ActiveMove active;
  std::vector<std::string> log;
  void pushLog(const std::string& m) {
    log.push_back(m);
    if (log.size() > kLogMax) log.erase(log.begin(), log.begin() + (log.size() - kLogMax));
  }
  float press_gap_s = 1.0f;
  std::map<int, std::string> button_map{{2, "wink:L"}, {3, "wink:R"}, {4, "wave:B"}};
  bool headlamps_on = false;
  bool allow_with_lamps_on = false;
  int press_count = 0;
  float press_timer = 0.0f;
  std::map<std::string, std::string> aux_map{{"aux1", "up:B"}, {"aux2", "wave:B"}};
  std::map<std::string, bool> aux_loop{{"aux1", false}, {"aux2", false}};
  struct LoopState {
    std::string aux;
    std::string action;
    bool has() const { return !aux.empty(); }
  } loop;

  void boot() {
    state = State::OEM_PASS;
    oem_path_ok = true;
    left.moving = right.moving = false;
    active = ActiveMove{};
    queue.clear();
    fault.clear();
    wdt_last_feed = time_s;
    press_count = 0;
    press_timer = 0.0f;
    loop = LoopState{};
    pushLog("boot->OEM_PASS");
  }

  void power_loss() {
    boot();
    ble_connected = false;
    pushLog("power_loss->OEM_PASS");
  }

  void feed_watchdog() { wdt_last_feed = time_s; }

  bool pair(bool pin_ok) {
    if (pin_ok) {
      bonded = true;
      pushLog("paired");
      return true;
    }
    return false;
  }

  void ble_connect(bool bonded_device) {
    ble_connected = true;
    bonded_link = bonded_device;
    if (state == State::OEM_PASS) state = State::IDLE;
    pushLog(std::string("ble_connect bonded=") + (bonded_device ? "1" : "0"));
  }

  void ble_disconnect() {
    ble_connected = false;
    queue.clear();
    loop = LoopState{};
    if (!active.has()) state = fault.empty() ? State::IDLE : State::FAULT;
    pushLog("ble_disconnect->cancel_queue");
  }

  bool auth_ok(bool authenticated) {
    if (!(ble_connected && bonded_link && bonded && authenticated)) {
      invalid_streak++;
      if (invalid_streak >= 5) lockout_until = time_s + kLockoutS;
      return false;
    }
    return true;
  }

  bool rate_ok() {
    if (time_s < lockout_until) return false;
    std::vector<float> kept;
    for (float t : cmd_times)
      if (time_s - t < 1.0f) kept.push_back(t);
    cmd_times = kept;
    if ((int)cmd_times.size() >= kRateLimitPerS) {
      lockout_until = time_s + kLockoutS;
      return false;
    }
    cmd_times.push_back(time_s);
    return true;
  }

  bool set_sleepy(const std::string& side, float value, bool authenticated = true) {
    if (!auth_ok(authenticated) || !rate_ok()) return false;
    if (!(kValidSleepyLo <= value && value <= kValidSleepyHi)) {
      invalid_streak++;
      return false;
    }
    invalid_streak = 0;
    sleepy[side] = value;
    return true;
  }
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
